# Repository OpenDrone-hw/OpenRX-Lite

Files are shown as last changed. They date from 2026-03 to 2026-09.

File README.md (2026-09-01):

# OpenRX Lite

Open-source 2.4 GHz ExpressLRS receiver for small FPV aircraft. OpenRX Lite
combines an ESP32-C3 and SX1281 with an on-board ceramic link antenna in a
10.0 x 11.5 mm board.

<p>
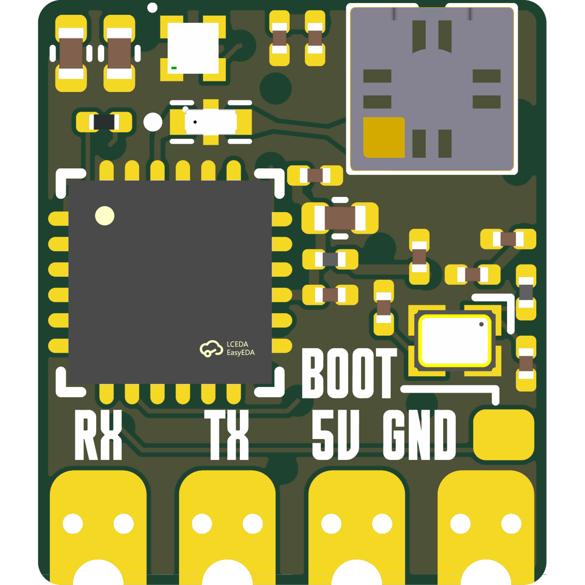
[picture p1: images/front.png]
OpenRX Lite front

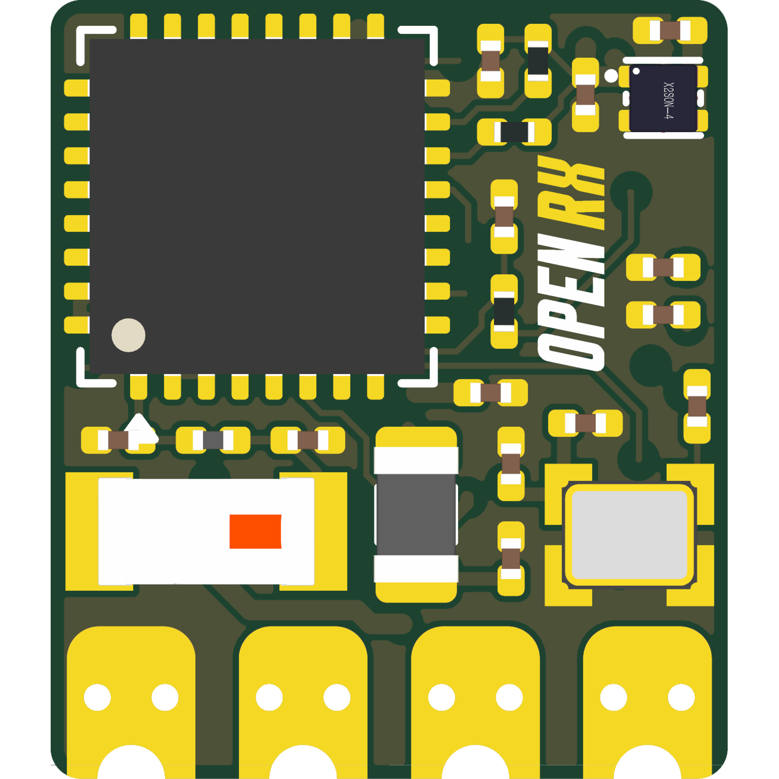
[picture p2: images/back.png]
OpenRX Lite back

</p>







## Specifications

| | |
|---|---|
| Band | 2.4 GHz |
| Radio | SX1281 |
| Antenna | On-board ceramic |
| Telemetry power | 13 dBm (20 mW) |
| Protocol | CRSF |
| MCU | ESP32-C3 |
| Input | 5 V pad |
| Firmware | ExpressLRS |
| Flashing | Betaflight passthrough or Wi-Fi |
| Dimensions | 10.0 x 11.5 mm |
| PCB | 6-layer, 1.0 mm |

Technical write-up, part list and layout constraints: [AGENTS.md](AGENTS.md).

## In the line

What pairs with what, and what is available:
[opendrone.be](https://opendrone.be).

## Contributing

See [CONTRIBUTING.md](CONTRIBUTING.md).

## License

Hardware licensed under [CERN-OHL-S-2.0](https://ohwr.org/cern_ohl_s_v2.txt),
see [LICENSE](LICENSE).

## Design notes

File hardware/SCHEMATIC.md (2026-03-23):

# OpenRX-Lite Schematic Documentation

Budget 2.4GHz ExpressLRS receiver. No PA/LNA, no UFL -- direct SX1281 to ceramic chip antenna.

- PCB: 16x12mm, 2-layer, 1.0mm thickness
- Target BOM: EUR 3-4
- Input: 3.3-5V from flight controller

## Block Diagram

```
                                    +3.3V
                                      |
  +-----+    +--------+    +---------+----------+
  | FC   |    |ME6211  |    |                    |
  | 5V---|----| LDO    |----|  ESP32-C3FH4       |
  | GND--|--+-| 3.3V   |    |  (QFN-32, 5x5mm)  |
  | TX---|--|-|--------|----| GPIO1/RX           |
  | RX---|--|-|--------|----| GPIO0/TX           |
  +-----+  | |        |    |                    |    SPI Bus
            | +--------+    |  GPIO4/SCK  -------+--------+
            |               |  GPIO7/MOSI -------+-----+  |
            |               |  GPIO6/MISO -------+--+  |  |
            |               |  GPIO8/NSS  -------+-+|  |  |
            |               |  GPIO5/DIO1 ------+| ||  |  |
            |               |  GPIO3/BUSY -----+|| ||  |  |
            |               |  GPIO2/NRST ----+||| ||  |  |
            |               |                 |||| ||  |  |
            |     40MHz     |  XTAL_P/N       |||| ||  |  |
            |    +-----+    |    |  |          |||| ||  |  |
            |    | XTAL|----+----+--+          |||| ||  |  |
            |    +-----+    |                  |||| ||  |  |
            |               | GPIO10 ---> WS2812B (opt)    |
            |               | GPIO9  ---> BOOT btn         |
            |               | GPIO18 ---> USB D- (TP)      |
            |               | GPIO19 ---> USB D+ (TP)      |
            |               +----------+   |||| ||  |  |
            |                              |||| ||  |  |
            |               +----------+   |||| ||  |  |
            |    52MHz      |SX1281    |   |||| ||  |  |
            |   +------+    |IMLTRT   |   |||| ||  |  |
            |   | TCXO |----|XTA      |   |||| ||  |  |
            |   +------+    |         |   |||| ||  |  |
            |               |NRESET---+---+||| ||  |  |
            |               |BUSY  --------+|| ||  |  |
            |               |DIO1  ---------+| ||  |  |
            |               |NSS   ----------+ ||  |  |
            |               |MISO  -------------+  |  |
            |               |MOSI  ----------------+  |
            |               |SCK   -------------------+
            |               |         |
            |               |  RFIO   |
            |               +----+----+
            |                    |
            |               L-match network
            |               2.2nH + 1.0pF
            |                    |
            |               +----------+
            |               | Ceramic  |
            |               | Antenna  |
            |               | 2450AT   |
            |               +----------+
            |
            +--- GND plane
```

## Power Supply (U3: ME6211C33M5G-N)

SOT-23-5, 500mA, LDO 3.3V regulator. LCSC C82942.

```
         5V IN
          |
          +--+--[C1 10uF]--+--GND
          |  |              |
          |  +--[C2 100nF]--+
          |
     +----+----+
     |1  VIN   |
     |         |
     |2  VOUT--+--+--[C3 22uF]--+--GND
     |         |  |              |
     |3  CE    |  +--[C4 100nF]--+
     |   (=VIN)|  |
     |4  GND   |  +--- 3.3V RAIL
     |5  NC    |
     +---------+
```

### Pin-by-pin: ME6211C33M5G-N (SOT-23-5)

| Pin | Name | Connection |
|-----|---|---|
| 1 | VIN | 5V input rail. C1 (10uF 0603 X5R) + C2 (100nF 0402 X7R) to GND |
| 2 | VOUT | 3.3V output rail. C3 (22uF 0603 X5R) + C4 (100nF 0402 X7R) to GND |
| 3 | CE (chip enable) | Tied to VIN (always on) |
| 4 | GND | Ground |
| 5 | NC | No connect |

## ESP32-C3FH4 (U1, QFN-32, 5x5mm)

LCSC C2858491. RISC-V single core, 160MHz, 4MB internal flash, WiFi+BLE.

### Pin-by-pin: ESP32-C3FH4 (QFN-32)

| Pin | Name | Connection | Notes |
|-----|---|---|---|
| 1 | GND | GND | |
| 2 | GND | GND | |
| 3 | 3V3 | 3.3V rail, 100nF (C5) to GND | Main power |
| 4 | EN (CHIP_EN) | 10k (R1) pull-up to 3.3V + 1uF (C6) to GND | RC delay per Espressif spec. Provides stable power-on reset. |
| 5 | GPIO4 | SX1281 SCK (pin 18) | SPI clock |
| 6 | GPIO5 | SX1281 DIO1 (pin 5) | Radio interrupt (active high) |
| 7 | GPIO6 | SX1281 MISO (pin 16) | SPI data from radio |
| 8 | GPIO7 | SX1281 MOSI (pin 17) | SPI data to radio |
| 9 | GPIO8 | SX1281 NSS (pin 19) + 10k (R2) pull-up to 3.3V | SPI chip select (active low). Pull-up keeps radio deselected during ESP boot. |
| 10 | GPIO9 | BOOT button (SW1) to GND + 10k (R3) pull-up to 3.3V | Hold low during reset to enter USB/UART bootloader. Internal pull-up exists but external recommended. |
| 11 | GPIO10 | WS2812B LED data (D1) | Optional status LED. Series 100R (R4) recommended. |
| 12 | GND | GND | |
| 13 | GPIO18 (USB_D-) | Test pad TP1 | Native USB for flashing. Optional -- can use UART instead. |
| 14 | GPIO19 (USB_D+) | Test pad TP2 | Native USB for flashing. Optional. |
| 15 | GPIO3 | SX1281 BUSY (pin 4) | Radio busy status (active high). Poll before SPI commands. |
| 16 | GPIO2 | SX1281 NRESETn (pin 3) | Radio hardware reset (active low). ESP drives low to reset SX1281. |
| 17 | GPIO1 (RX) | FC connector pad TX (CRSF from FC) | UART RX. FC TX connects to ESP RX. 3.3V logic. |
| 18 | GPIO0 (TX) | FC connector pad RX (CRSF to FC) | UART TX. ESP TX connects to FC RX. |
| 19 | GND | GND | |
| 20 | XTAL_P | 40MHz crystal (Y1) pin 1 + 10pF (C7) to GND | Crystal load cap. Place crystal close to pins 20/21. |
| 21 | XTAL_N | 40MHz crystal (Y1) pin 3 + 10pF (C8) to GND | Crystal load cap. |
| 22-30 | GND/NC | GND or NC per datasheet | Unused GPIO and supply pins tied to GND |
| 31 | GND | GND | |
| 32 | GND | GND | |
| EP | Exposed pad | GND | Thermal pad, multiple vias to ground plane |

**Critical notes for ESP32-C3FH4:**
- Pin 4 (EN) RC time constant: 10k * 1uF = 10ms. This ensures clean power-on reset.
- GPIO9 is the boot mode strapping pin. HIGH = normal boot from flash. LOW during reset = download mode.
- GPIO8 is also a strapping pin. Must be HIGH during boot (pull-up on NSS line handles this).
- GPIO2 is a strapping pin. Defaults to HIGH (floating). OK since SX1281 NRESET is active low.
- The ESP32-C3FH4 has 4MB flash internal -- no external flash needed.
- 40MHz crystal is mandatory. Cannot use internal RC oscillator for WiFi/BLE.
- Thermal pad MUST be soldered to GND with thermal vias.

## SX1281IMLTRT (U2, QFN-24, 4x4mm)

LCSC C2151551. 2.4GHz LoRa/FLRC/FSK transceiver. Used in LDO mode (no external inductor).

### Pin-by-pin: SX1281IMLTRT (QFN-24)

| Pin | Name | Connection | Notes |
|-----|---|---|---|
| 1 | VDD | 3.3V through 100nF (C9) to GND | Digital supply |
| 2 | VDD_IN | 3.3V through 100nF (C10) to GND | CRITICAL: Must be connected. Main power input for internal LDO/DC-DC. |
| 3 | NRESETn | ESP32-C3 GPIO2 (pin 16) + 10k (R5) pull-up to 3.3V + 100nF (C11) to GND | Active low reset. RC provides power-on reset. ESP can drive low for hard reset. |
| 4 | BUSY | ESP32-C3 GPIO3 (pin 15) | Active high when radio is processing a command. Poll before SPI transactions. |
| 5 | DIO1 | ESP32-C3 GPIO5 (pin 6) | Main interrupt output. Directly connected. |
| 6 | DIO2 | NC | Not used in this design. Can be used for RF switch control in designs with PA/LNA. |
| 7 | DIO3 | NC | Not used. Can output 32MHz clock for TCXO enable but we use always-on TCXO. |
| 8 | GND | GND | |
| 9 | GND | GND | |
| 10 | VR_PA | 470nF (C12) to GND | LDO mode: This is the PA regulator output. 470nF decoupling required. NO inductor (inductor only needed in DC-DC mode). |
| 11 | VDD | 3.3V through 100nF (C13) to GND | RF/analog supply |
| 12 | XTA | 52MHz TCXO output (Y2 pin 3) | TCXO clock input. AC coupling cap may be needed (10pF, C14) depending on TCXO output type. If TCXO is clipped sine output, direct connection OK. |
| 13 | XTB | NC (floating) | Only used in crystal mode. Leave floating for TCXO mode. |
| 14 | GND | GND | |
| 15 | RFIO | L-match network to antenna | See RF Path section below |
| 16 | MISO | ESP32-C3 GPIO6 (pin 7) | SPI data output |
| 17 | MOSI | ESP32-C3 GPIO7 (pin 8) | SPI data input |
| 18 | SCK | ESP32-C3 GPIO4 (pin 5) | SPI clock input |
| 19 | NSS | ESP32-C3 GPIO8 (pin 9) + 10k (R2) pull-up to 3.3V | SPI chip select, active low. Shared pull-up with ESP side. |
| 20 | GND | GND | |
| 21 | GND | GND | |
| 22 | GND | GND | |
| 23 | GND | GND | |
| 24 | GND | GND | |
| EP | Exposed pad | GND | Thermal pad. Multiple vias to GND plane. |

**Critical notes for SX1281:**
- LDO mode selected: VR_PA (pin 10) gets 470nF cap only. No inductor.
- DC-DC mode would require 15nH inductor on VR_PA but adds layout complexity on 2-layer board. Not worth it for a receiver.
- VDD_IN (pin 2) MUST be connected to 3.3V. Common mistake to leave it floating.
- TCXO mode: Set register UseRegulatorMode and configure TCXO in firmware. DIO3 can control TCXO power but we run TCXO always-on from 3.3V for simplicity.
- Max SPI clock: 16MHz. ESP32-C3 SPI peripheral should be configured accordingly.
- BUSY must be polled before every SPI transaction. Do not rely on timing.

## 52MHz TCXO (Y2: OW7EL89CENUNFAYLC-52M)

LCSC C22434896. SMD 2016-4P (2.0x1.6mm). YXC, 3.3V, +/-0.5ppm.

### Pin-by-pin: TCXO (SMD2016-4P)

| Pin | Name | Connection |
|-----|---|---|
| 1 | VDD | 3.3V through 100nF (C15) to GND |
| 2 | GND | GND |
| 3 | OUTPUT | SX1281 XTA (pin 12). Direct connection if clipped sine output. Add 10pF AC coupling cap (C14) if DC blocking needed. |
| 4 | GND | GND |

**Notes:**
- TCXO provides temperature-stable 52MHz reference. Prevents frequency drift disconnections that plague crystal-based ELRS receivers.
- +/-0.5ppm stability is excellent. SX1281 datasheet requires better than +/-5ppm for reliable FLRC mode.
- Always-on (powered from 3.3V rail directly). No DIO3 control needed.
- Place close to SX1281 XTA pin. Keep trace short and away from digital signals.

## 40MHz Crystal (Y1: CJ17-400001010B20)

LCSC C2875272. SMD 1612-4P (1.6x1.2mm). Changjing, 10pF load, +/-10ppm.

### Pin-by-pin: Crystal (SMD1612-4P)

| Pin | Name | Connection |
|-----|---|---|
| 1 | XIN | ESP32-C3 XTAL_P (pin 20) + 10pF (C7) to GND |
| 2 | GND | GND |
| 3 | XOUT | ESP32-C3 XTAL_N (pin 21) + 10pF (C8) to GND |
| 4 | GND | GND |

**Notes:**
- 10pF load caps match crystal specification. Actual capacitance seen by crystal = (C_load1 * C_load2) / (C_load1 + C_load2) + C_stray. With 10pF caps and ~2-3pF stray, effective load is ~7-8pF. May need to adjust to 12pF caps if frequency is off.
- Place as close to ESP32-C3 XTAL pins as possible. Route traces as short differential pair.
- Guard ring on GND plane around crystal traces recommended.
- Keep copper pour away from crystal on the other layer.

## RF Path (Antenna Matching)

No PA/LNA. Direct connection from SX1281 RFIO to ceramic antenna through L-match network.

```
SX1281          L-match              Ceramic Antenna
RFIO  ---[L1 2.2nH]---+---[feed]--- 2450AT18A100E
(pin 15)               |             (Johanson)
                   [C16 1.0pF]
                       |
                      GND
```

### Components:
- L1: 2.2nH inductor, 0402, high-Q (>30 at 2.4GHz). LCSC basic part preferred.
- C16: 1.0pF capacitor, 0402, C0G/NP0. Tight tolerance (+/-0.1pF if possible).

### Ceramic Antenna: 2450AT18A100E (ANT1)

LCSC C89334. Johanson, 3.2x1.6mm chip antenna.

**Notes:**
- Antenna MUST be placed at PCB edge with ground plane keepout per Johanson application note.
- Minimum 1mm clearance from antenna feed to GND pour on top layer.
- Ground plane on bottom layer should extend under antenna for return path.
- Antenna impedance is nominally 50 ohm but varies with ground plane geometry. L-match values (2.2nH/1.0pF) are starting points -- tune with VNA on actual PCB.
- No copper (signal or ground) on the same layer as antenna within keepout zone.
- Performance will be significantly worse than external antenna. Expected range: 200-500m line of sight with ELRS 500Hz mode. Adequate for typical FPV use (proximity/indoor/whoops).

## WS2812B LED (D1, Optional)

Standard addressable RGB LED for status indication.

| Connection | Detail |
|---|---|
| VDD | 3.3V (WS2812B works at 3.3V, some variants need 5V -- check datasheet) |
| DIN | ESP32-C3 GPIO10 (pin 11) through 100R series resistor (R4) |
| DOUT | NC |
| GND | GND |
| Decoupling | 100nF (C17) close to VDD pin |

Note: WS2812B is optional. Omit to save BOM cost and board space. ELRS firmware can function without LED.

## Boot Button (SW1)

Tactile switch, normally open.

| Connection | Detail |
|---|---|
| One side | ESP32-C3 GPIO9 (pin 10) |
| Other side | GND |
| Pull-up | 10k (R3) from GPIO9 to 3.3V |

Hold button during power-on or reset to enter bootloader (USB or UART download mode).

Note: For production, this can be replaced with solder pads or omitted entirely if UART flashing via FC connection is sufficient. ELRS uses its own bootloader passthrough via UART.

## Connector Pads (J1)

4 castellated or solder pads, 1.27mm pitch, at PCB edge.

| Pad | Signal | Notes |
|-----|---|---|
| 1 | 5V | Power input from FC. 3.3-5V range (LDO input). |
| 2 | GND | Ground |
| 3 | TX | ESP32-C3 GPIO0/TX. CRSF data TO flight controller. Connect to FC RX pad. |
| 4 | RX | ESP32-C3 GPIO1/RX. CRSF data FROM flight controller. Connect to FC TX pad. |

## Test Pads

| Pad | Signal | Notes |
|-----|---|---|
| TP1 | USB D- | ESP32-C3 GPIO18. For USB flashing during development. |
| TP2 | USB D+ | ESP32-C3 GPIO19. For USB flashing during development. |

## Complete Decoupling Capacitor Summary

| Designator | Value | Package | Location | IC/Pin |
|---|---|---|---|---|
| C1 | 10uF | 0603 X5R 10V | LDO input | U3 VIN |
| C2 | 100nF | 0402 X7R 16V | LDO input | U3 VIN |
| C3 | 22uF | 0603 X5R 10V | LDO output | U3 VOUT |
| C4 | 100nF | 0402 X7R 16V | LDO output | U3 VOUT |
| C5 | 100nF | 0402 X7R 16V | ESP32 3V3 | U1 pin 3 |
| C6 | 1uF | 0402 X5R 10V | ESP32 EN | U1 pin 4 (with R1) |
| C7 | 10pF | 0402 C0G 50V | Crystal load | U1 XTAL_P (pin 20) |
| C8 | 10pF | 0402 C0G 50V | Crystal load | U1 XTAL_N (pin 21) |
| C9 | 100nF | 0402 X7R 16V | SX1281 VDD | U2 pin 1 |
| C10 | 100nF | 0402 X7R 16V | SX1281 VDD_IN | U2 pin 2 |
| C11 | 100nF | 0402 X7R 16V | SX1281 NRESET | U2 pin 3 (with R5) |
| C12 | 470nF | 0402 X5R 10V | SX1281 VR_PA | U2 pin 10 (LDO mode) |
| C13 | 100nF | 0402 X7R 16V | SX1281 VDD | U2 pin 11 |
| C14 | 10pF | 0402 C0G 50V | TCXO AC coupling | Y2 out to U2 XTA (optional) |
| C15 | 100nF | 0402 X7R 16V | TCXO VDD | Y2 pin 1 |
| C16 | 1.0pF | 0402 C0G 50V | Antenna match | Shunt to GND in L-match |
| C17 | 100nF | 0402 X7R 16V | WS2812B VDD | D1 (optional) |

## Complete Resistor Summary

| Designator | Value | Package | Location |
|---|---|---|---|
| R1 | 10k | 0402 | ESP32 EN pull-up |
| R2 | 10k | 0402 | SPI NSS pull-up (shared ESP/SX1281) |
| R3 | 10k | 0402 | BOOT button pull-up |
| R4 | 100R | 0402 | WS2812B data series resistor (optional) |
| R5 | 10k | 0402 | SX1281 NRESET pull-up |

## Complete Inductor Summary

| Designator | Value | Package | Location |
|---|---|---|---|
| L1 | 2.2nH | 0402 | Antenna L-match series inductor |

## Design Notes and Considerations

### Power Budget
- ESP32-C3 active (WiFi off, CPU running): ~30mA
- SX1281 RX mode: ~7mA
- SX1281 TX mode (no PA): ~25mA at +12.5dBm
- TCXO: ~1.5mA
- WS2812B: ~1mA idle, ~20mA full white
- Total typical (RX mode): ~40mA
- ME6211 500mA capacity provides ample margin

### Layout Priorities (2-layer board)
1. SX1281 ground pad: Maximize thermal vias to bottom GND plane
2. ESP32-C3 ground pad: Same treatment
3. Crystal placement: As close to ESP XTAL pins as physically possible
4. TCXO placement: As close to SX1281 XTA as possible
5. Antenna: At PCB edge, ground plane keepout per Johanson app note
6. Decoupling caps: Each cap within 1mm of its associated IC pin
7. SPI traces: Keep short, matched length not critical at 16MHz max
8. RF trace (RFIO to antenna): 50 ohm controlled impedance if possible. On 2-layer 1.0mm FR4, approximately 1.8mm trace width for 50 ohm microstrip. Short trace length minimizes mismatch impact.

### 2-Layer Stackup (JLCPCB 1.0mm)
- Top: Components, signal routing, RF trace
- Bottom: Continuous GND plane (maximise pour). Route signals on top only where possible.

### Firmware Considerations
- ExpressLRS firmware must be configured for:
  - SX1281 (not SX1280 -- SX1281 has LNA built in)
  - TCXO mode (not crystal)
  - LDO mode (not DC-DC)
  - No PA/LNA control pins
  - GPIO mappings matching this schematic
- CRSF protocol on UART at 420000 baud (ELRS default)
- Binding phrase set in firmware build

### Known Limitations
- No diversity (single antenna, single radio)
- No PA: TX power limited to SX1281 native +12.5dBm max
- No LNA: RX sensitivity limited to SX1281 native (~-105dBm for LoRa, ~-98dBm for FLRC)
- Range estimate: 200-500m LOS at 500Hz, 1-2km at 50Hz. Adequate for proximity/indoor/whoop flying.
- 2-layer RF: Impedance control less precise than 4-layer. Antenna match will need bench tuning.
- Ceramic antenna: ~2-3dB gain penalty vs external dipole/T-antenna

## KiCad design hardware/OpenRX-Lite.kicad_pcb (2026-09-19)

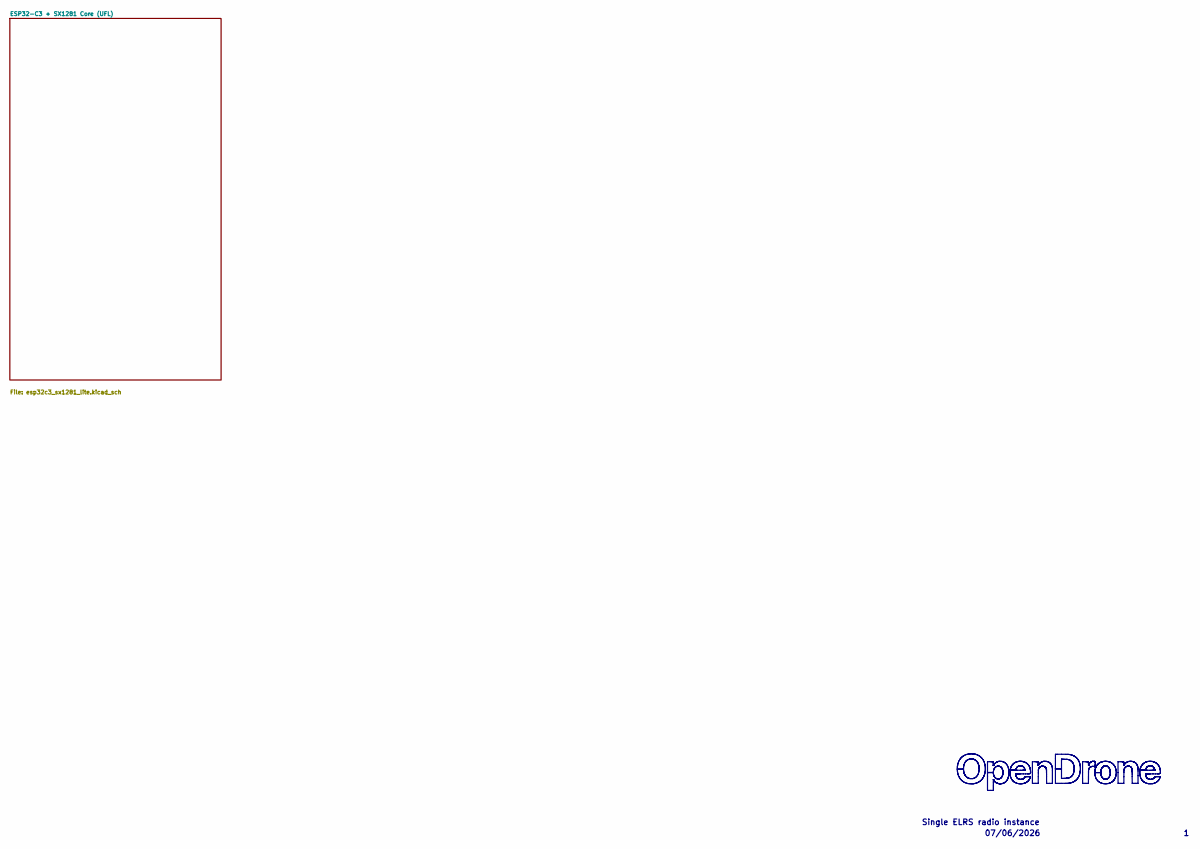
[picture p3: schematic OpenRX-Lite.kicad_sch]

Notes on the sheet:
07/06/2026
Single ELRS radio instance

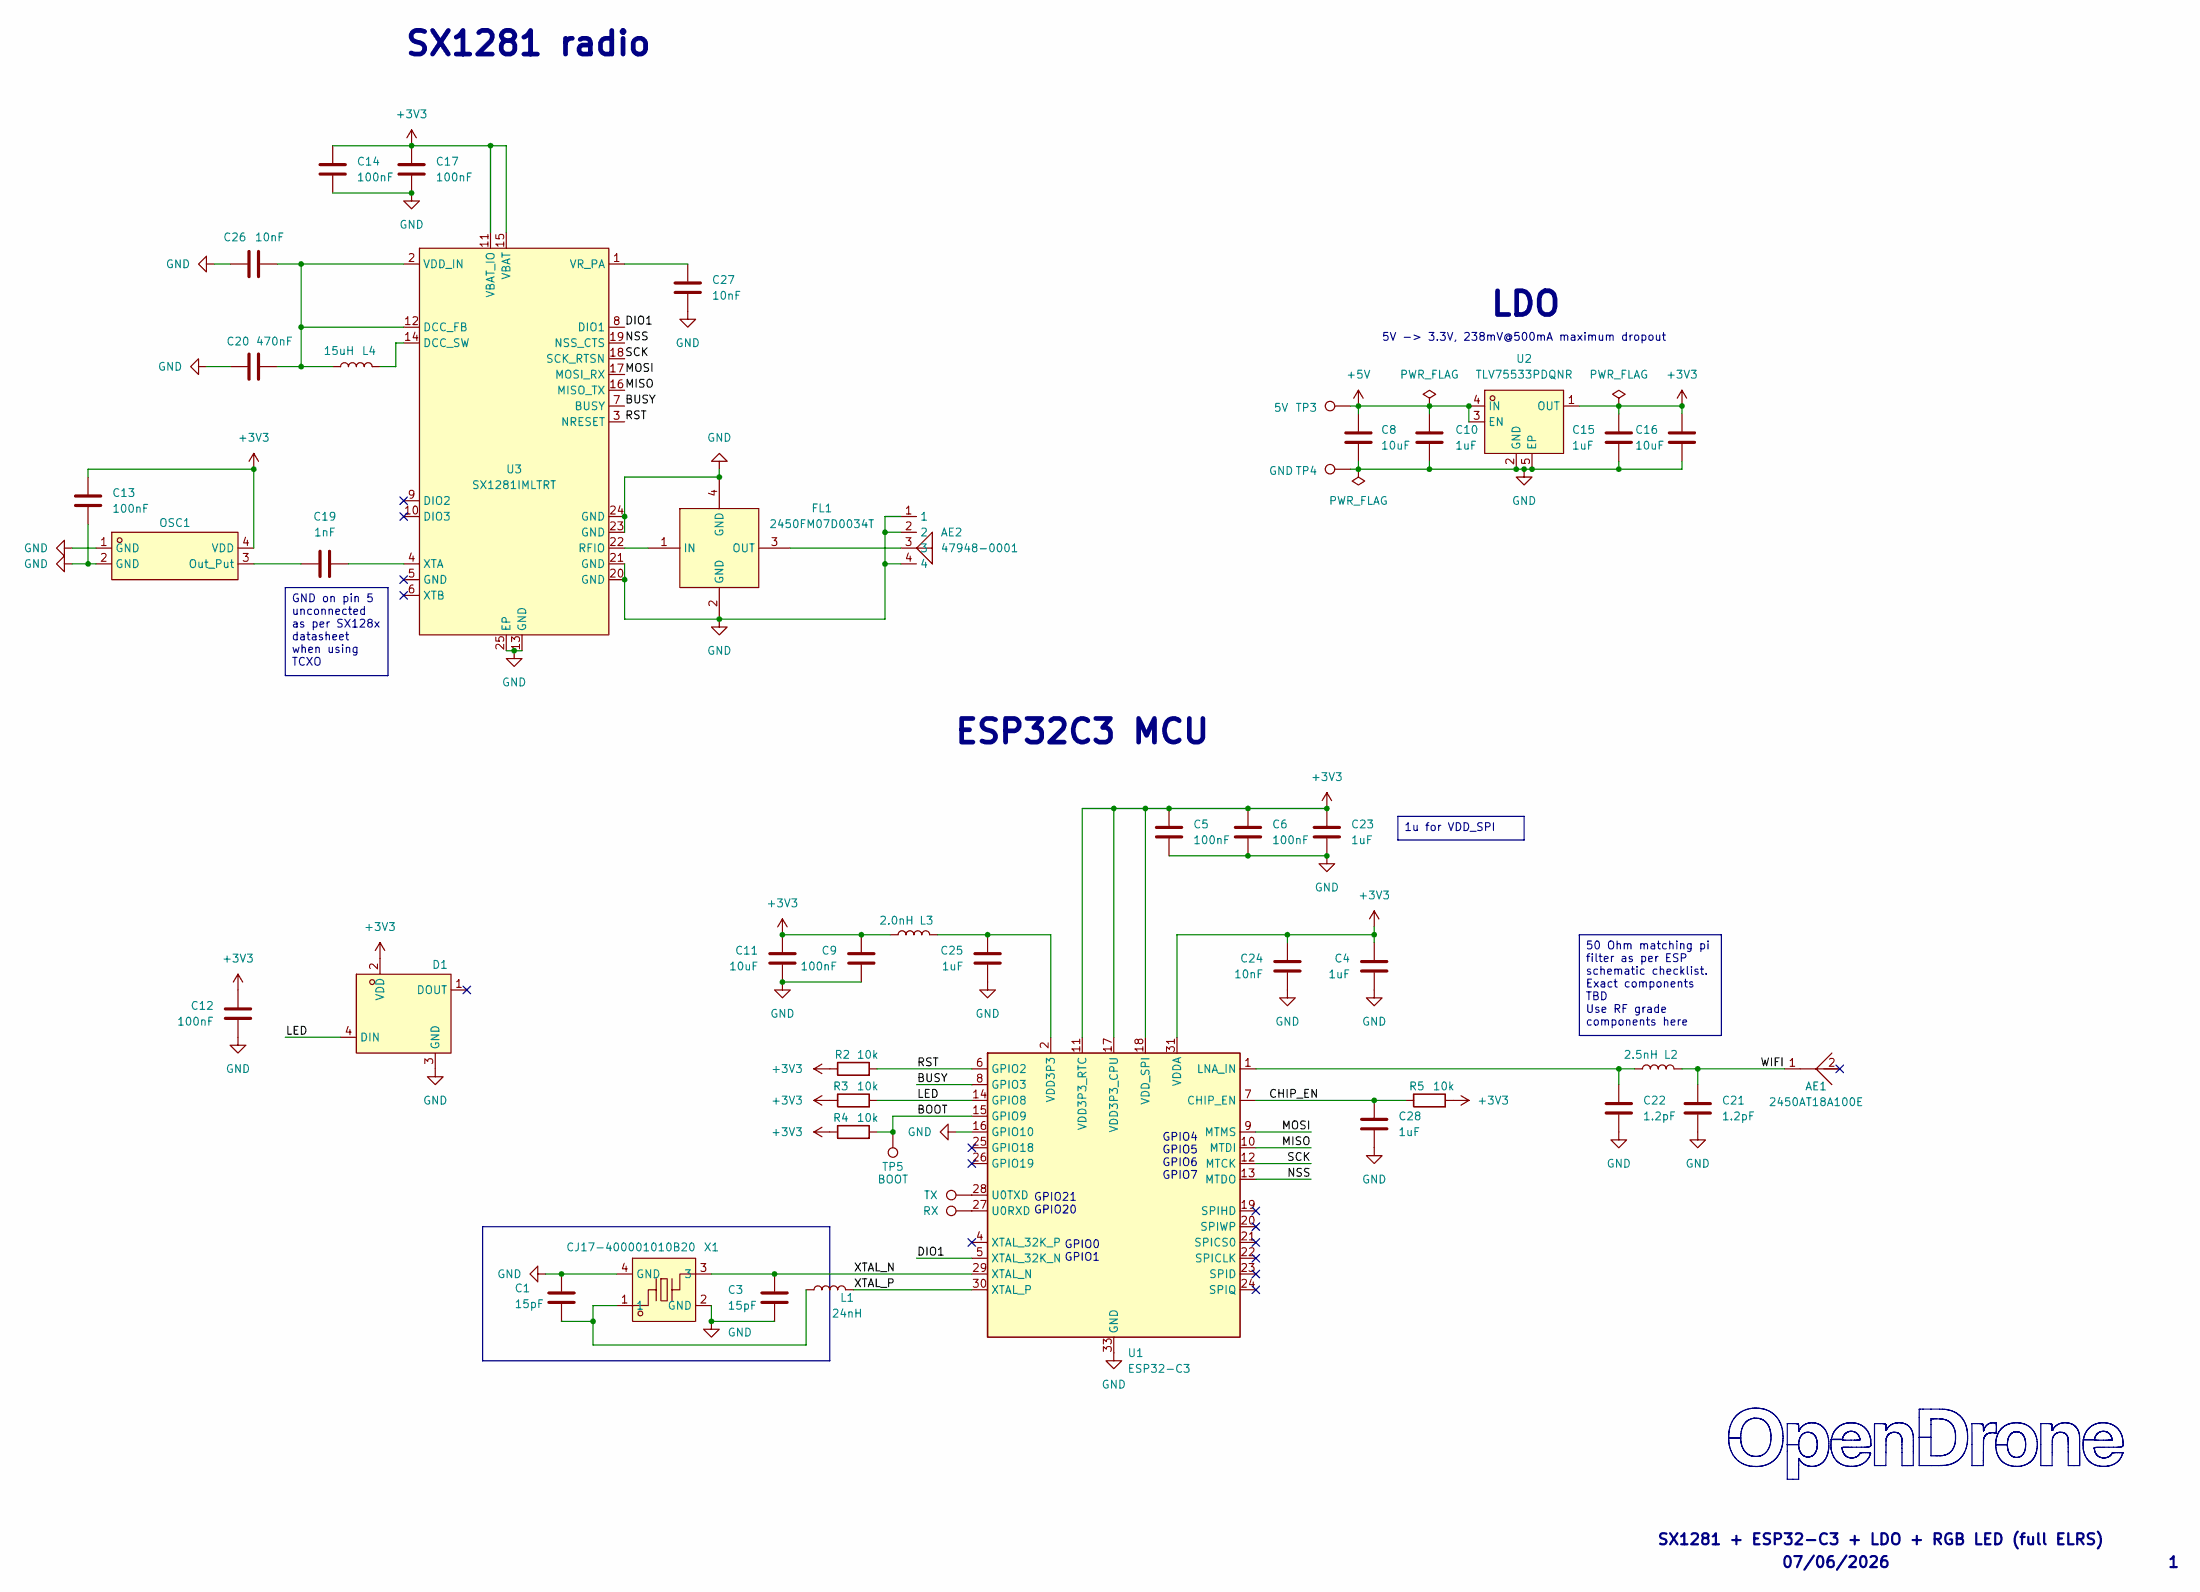
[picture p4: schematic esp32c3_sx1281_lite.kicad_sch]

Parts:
AE1: 2450AT18A100E; ANT-SMD_L3.2-W1.6; MPN 2450AT18A100E; LCSC Part C89334
AE2: 47948-0001; ANT-SMD_47948-0001; MPN 479480001; LCSC C152351
C1, C3: 15pF; C_0201_0603Metric; MPN GRM0335C1H150JA01D; LCSC C85891
C4, C10, C15, C23, C25, C28: 1uF; C_0201_0603Metric; MPN GRM033R61A105ME44D; LCSC C76935
C5, C6, C9, C12, C13, C14, C17: 100nF; C_0201_0603Metric; MPN GRM033R61E104KE14D; LCSC C76939
C8, C16: 10uF; C_0402_1005Metric; MPN CL05A106MQ5NUNC; LCSC C15525
C11: 10uF; C_0402_1005Metric; MPN GRM155R60J106ME44D; LCSC C76991
C19: 1nF; C_0201_0603Metric; MPN 0201B102K500NT; LCSC C66942
C20: 470nF; C_0201_0603Metric; MPN GRM033R60J474KE90D; LCSC C85926
C21, C22: 1.2pF; C_0201_0603Metric; MPN GRM0335C1H1R2BA01D; LCSC C85895
C24, C26, C27: 10nF; C_0201_0603Metric; MPN GRM033R61A103KA01J; LCSC C2168164
D1: XL-1010RGBC-WS2812B; LED-SMD_4P-L1.0-W1.0-TL_XL-1010RGBC-WS2812B; MPN XL-1010RGBC-2812B; LCSC C5349953
FL1: 2450FM07D0034T; FILTER-SMD_4P-L1.0-W0.5-L; MPN 2450FM07D0034T; LCSC Part_1 C2651081
L1: 24nH; L_0201_0603Metric; MPN LQP03TN24NH02D; LCSC C206441
L2: 2.5nH; L_0201_0603Metric; MPN LQP03TN2N5C02D; LCSC C206435
L3: 2.0nH; L_0201_0603Metric; MPN LQP03TN2N0B02D; LCSC C86125
L4: 15uH; L_0805_2012Metric; MPN MLZ2012M150WT000; LCSC C383402
OSC1: OW7EL89CENUNFAYLC-52M; OSC-SMD_4P-L2.0-W1.6-BL_TXC_7Z; MPN OW7EL89CENUNFAYLC-52M; LCSC Part C22434896
R2, R3, R4, R5: 10k; R_0201_0603Metric; MPN RC0201FR-0710KL; LCSC C106225
TP1: RX; SolderPad_1.2x2.0mm
TP2: TX; SolderPad_1.2x2.0mm
TP3: 5V; SolderPad_1.2x2.0mm
TP4: GND; SolderPad_1.2x2.0mm
TP5: BOOT; SolderPad_1.2x2.0mm
U1: ESP32-C3; QFN-32-1EP_5x5mm_P0.5mm_EP3.7x3.7mm; MPN ESP32-C3FH4; LCSC C2858491
U2: TLV75533PDQNR; X2SON-4_L1.0-W1.0-P0.65-TL-EP; MPN TLV75533PDQNR; LCSC Part C2861882
U3: SX1281IMLTRT; QFN-24_L4.0-W4.0-P0.50-TL-EP2.6; MPN SX1281IMLTRT; LCSC Part C2151551
X1: CJ17-400001010B20; CRYSTAL-SMD_4P-L1.6-W1.2-BL; MPN CJ17-400001010B20; LCSC Part C2875272

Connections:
+3V3: C4.1, C5.1, C6.1, C9.1, C11.1, C12.1, C13.1, C14.1, C15.1, C16.1, C17.1, C23.1, C24.1, D1.2 (VDD), L3.2, OSC1.4 (VDD), R2.1, R3.1, R4.1, R5.2, U1.11 (VDD3P3_RTC), U1.17 (VDD3P3_CPU), U1.18 (VDD_SPI), U1.31 (VDDA), U1.32 (VDDA), U2.1 (OUT), U3.11 (VBAT_IO), U3.15 (VBAT)
+5V: C8.1, C10.1, TP3.1 (1_1), U2.3 (EN), U2.4 (IN)
/ESP32-C3 + SX1281 Core (UFL)/BOOT: R4.2, TP5.1 (1_1), U1.15 (GPIO9)
/ESP32-C3 + SX1281 Core (UFL)/BUSY: U1.8 (GPIO3), U3.7 (BUSY)
/ESP32-C3 + SX1281 Core (UFL)/CHIP_EN: C28.1, R5.1, U1.7 (CHIP_EN)
/ESP32-C3 + SX1281 Core (UFL)/DIO1: U1.5 (XTAL_32K_N), U3.8 (DIO1)
/ESP32-C3 + SX1281 Core (UFL)/LED: D1.4 (DIN), R3.2, U1.14 (GPIO8)
/ESP32-C3 + SX1281 Core (UFL)/MISO: U1.10 (MTDI), U3.16 (MISO_TX)
/ESP32-C3 + SX1281 Core (UFL)/MOSI: U1.9 (MTMS), U3.17 (MOSI_RX)
/ESP32-C3 + SX1281 Core (UFL)/NSS: U1.13 (MTDO), U3.19 (NSS_CTS)
/ESP32-C3 + SX1281 Core (UFL)/RST: R2.2, U1.6 (GPIO2), U3.3 (NRESET)
/ESP32-C3 + SX1281 Core (UFL)/SCK: U1.12 (MTCK), U3.18 (SCK_RTSN)
/ESP32-C3 + SX1281 Core (UFL)/WIFI: AE1.1, C21.1, L2.1
/ESP32-C3 + SX1281 Core (UFL)/XTAL_N: C3.1, U1.29 (XTAL_N), X1.3
/ESP32-C3 + SX1281 Core (UFL)/XTAL_P: L1.2, U1.30 (XTAL_P)
GND: AE2.1, AE2.2, AE2.4, C1.2, C3.2, C4.2, C5.2, C6.2, C8.2, C9.2, C10.2, C11.2, C12.2, C13.2, C14.2, C15.2, C16.2, C17.2, C20.1, C21.2, C22.2, C23.2, C24.2, C25.2, C26.1, C27.2, C28.2, D1.3 (GND), FL1.2 (GND), FL1.4 (GND), OSC1.1 (GND), OSC1.2 (GND), TP4.1 (1_1), U1.16 (GPIO10), U1.33 (GND), U2.2 (GND), U2.5 (EP), U3.13 (GND), U3.20 (GND), U3.21 (GND), U3.23 (GND), U3.24 (GND), U3.25 (EP), X1.2 (GND), X1.4 (GND)
unnamed: C1.1, L1.1, X1.1
unnamed: C25.1, L3.1, U1.2 (VDD3P3), U1.3 (VDD3P3)
unnamed: FL1.1 (IN), U3.22 (RFIO)
unnamed: AE2.3, FL1.3 (OUT)
unnamed: C19.1, OSC1.3 (Out_Put)
unnamed: C22.1, L2.2, U1.1 (LNA_IN)
unnamed: TP1.1 (1_1), U1.27 (U0RXD)
unnamed: TP2.1 (1_1), U1.28 (U0TXD)
unnamed: C20.2, C26.2, L4.1, U3.2 (VDD_IN), U3.12 (DCC_FB)
unnamed: L4.2, U3.14 (DCC_SW)
unnamed: C27.1, U3.1 (VR_PA)
unnamed: C19.2, U3.4 (XTA)

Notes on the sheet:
5V -> 3.3V, 238mV@500mA maximum dropout
GPIO0 GPIO1
SX1281 + ESP32-C3 + LDO + RGB LED (full ELRS)
GPIO21 GPIO20
GPIO4 GPIO5 GPIO6 GPIO7
SX1281 radio
LDO
ESP32C3 MCU
07/06/2026
GND on pin 5 unconnected as per SX128x datasheet when using TCXO
1u for VDD_SPI
50 Ohm matching pi filter as per ESP schematic checklist. Exact components TBD Use RF grade components here

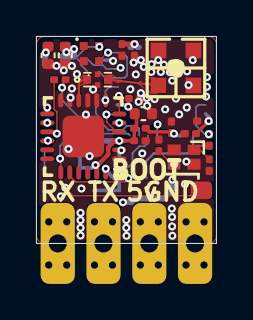
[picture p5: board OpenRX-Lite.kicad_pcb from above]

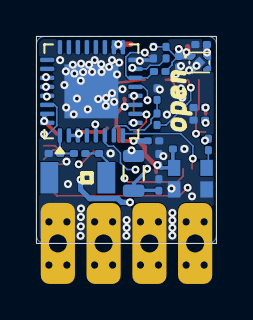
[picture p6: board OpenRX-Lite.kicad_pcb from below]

Board: 6 copper layers, 10.0 x 11.5 mm, 47 parts (22 on the bottom side), 28 nets.

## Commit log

2026-03-23 Initial repo: 6-receiver product lineup, core BOM, shared datasheets
    OpenRX is an open-source ExpressLRS 4.0 receiver family covering
    budget nano to Xrossband Gemini. All designs use ESP32-C3 MCU with
    SX1281 (2.4GHz) or LR1121 (dual-band) RF transceivers.
    CERN-OHL-S v2 licensed. Part of the OpenDrone ecosystem.
2026-03-23 Add OpenRX-Lite: budget 2.4GHz receiver (ESP32-C3 + SX1281)
    Smallest/cheapest receiver. No PA/LNA, ceramic antenna, 16x12mm.
    Includes SCHEMATIC.md, BOM.md, imported LCSC libs, datasheets.
    KiCad schematic/PCB are starter shells awaiting capture.
    [OpenRX-Lite.kicad_pcb, OpenRX-Lite.kicad_sch]
2026-03-23 Consolidate docs: 1 README + KICAD_WORKFLOW + 1 DESIGN.md per receiver
    - Merge SCHEMATIC.md + BOM.md into single DESIGN.md per receiver
    - Delete OPENRX_ELRS_4_RECEIVER_PORTFOLIO.md (content integrated)
    - Delete REPO_AUDIT_2026-03-23.md (issues addressed)
    - Fold CORE_BOM into README.md architecture table
    - Rename KICAD_WORKFLOW_AND_ELRS_COMPATIBILITY.md to KICAD_WORKFLOW.md
    - Rewrite KICAD_WORKFLOW with step-by-step capture instructions
    - Add shared libs and starter shared sheet from audit agent
    [OpenRX-Lite.kicad_sch]
2026-03-23 Fix all DESIGN.md: RFX2401C, DEA LPF, LR1121 pinout, FEM control
    - Lite: remove L-match network, use DEA102700LT-6307A2 only
    - Nano: clarify DEA LPF path, mark 0.3pF as mandatory, SE2431L as EOL
    - 900: fix LR1121 RFSW description, confirm 4x4mm package
    - Dual: SE2431L→RFX2401C, FEM via LR1121 RFSW not MCU GPIO, BOM $9→$7.62
    - PWM: SE2431L→RFX2401C, DEA LPF + 0.3pF path, BOM $7.40→$6.02
    - Gemini: SE2431L→RFX2401C, fix FEM control model, BOM $10.84→$9.46
    [OpenRX-Lite.kicad_sch]
2026-03-23 Update all DESIGN.md: TLV75533 X2SON LDO, XL-1010 1x1mm LED
    - Lite/Nano/900/Dual: ME6211 SOT-23-5 → TLV75533PDQNR X2SON-4 (1x1mm)
    - Gemini: keeps AP2112K (600mA needed for dual radios)
    - PWM: keeps AMS1117 (needs >6V input range)
    - All: WS2812B-2020 → XL-1010RGBC-WS2812B (1x1mm)
    - Updated cap values for TLV755 (1uF local + 10uF bulk)
    [OpenRX-Lite.kicad_sch]
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2026-03-23 Unify library tables, import RFX2401C, Lite schematic capture
    - All 6 projects now share OpenRX-Shared + OpenRX-Lite lib tables
    - Import RFX2401C (C19213) into shared library with 3D model path fix
    - OpenRX-Lite schematic: 0 ERC errors (captured in KiCad GUI)
    - Add .gitignore for .lck and .history files
    [OpenRX-Lite.kicad_pcb, OpenRX-Lite.kicad_sch]
2026-03-23 Separate Lite and Nano schematics, stop sharing one file
    Sharing one .kicad_sch between projects doesn't work - KiCad
    overwrites instance data when either project saves.
    - Lite: restored pre-Nano schematic as local esp32c3_sx1281_lite.kicad_sch
    - Nano: copied current shared sheet as local esp32c3_sx1281_rx_core.kicad_sch
    - Each project now has its own schematic file
    [OpenRX-Lite.kicad_sch, esp32c3_sx1281_lite.kicad_sch]
2026-03-23 Lite + Nano schematics: LCSC fields, fix 10uF to 0402, drop 0.3pF cap
    - All passives in both schematics have LCSC fields
    - 10uF caps fixed from 0201 to 0402 (C15525)
    - Nano C22 (0.3pF): removed discrete cap, use trace capacitance instead
    - 0 ERC errors on both schematics
    [esp32c3_sx1281_lite.kicad_sch]
2026-03-23 OpenRX-900: add all LCSC fields, fix 4.7uF to 0402
    - C20 (4.7uF): C23733, footprint fixed from 0201 to 0402
    - R5/R6/R7 (100k): C25741, RFSW pull-downs
    - L1 (10uH): C1035, 0603 DC-DC inductor
    - U4 (LR1121): C7498014
    - U5 (32MHz TCXO): C22434888
    - T1 (Johanson IPD): C19842466
    - JP1 (UFL): C88374
    - 0 ERC errors, all components have LCSC fields
2026-03-23 Fix crystal load caps: 10pF → 18pF (C71153) on all 4 receivers
    CJ17-400001010B20 crystal has CL=10pF. With 10pF load caps and
    ~2pF stray, effective load was only 7pF (30% low). Changed to 18pF
    giving ~11pF effective load, matching the crystal spec.
    C71153 = Samsung CL03C180JA3NNNC, 18pF C0G 25V 0201.
    [esp32c3_sx1281_lite.kicad_sch]
2026-03-23 Fix Gemini crystal load caps to 18pF (C62164), matching Lite and Mono
    [OpenRX-Lite.kicad_pcb, esp32c3_sx1281_lite.kicad_sch]
2026-03-23 OpenRX-Gemini: dual LR1121 schematic complete, 0 ERC errors
    - Radio 1 (U4): sub-GHz via Johanson IPD → JP1 UFL
    - Radio 2 (U9): 2.4GHz via RFX2401C (U10) → DEA (USB2) → JP3 UFL
    - Shared SPI bus (SCK/MISO/MOSI), separate NSS/IRQ/BUSY/RST per radio
    - Radio 2 control: GPIO10=NSS2, GPIO9=IRQ2, GPIO1=BUSY2, GPIO0=RST2
    - FEM driven by Radio 2 RFSW (DIO5→RXEN, DIO6→TXEN)
    - Radio 1 DIO5/DIO6 have 100k pull-downs (disconnected from FEM)
    - No LED (GPIO10 used for NSS2), no boot button (GPIO9 used for IRQ2)
    - Still needs: 10k pull-up on NSS2
    [esp32c3_sx1281_lite.kicad_sch]
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2026-03-23 Swap all solder pads to 1.2x2.0mm rounded (25%) across Lite, Mono, Gemini
    [esp32c3_sx1281_lite.kicad_sch]
2026-03-23 Swap 32MHz TCXO to smaller 2016 package (C22381772)
    OW2EL89 (3225, 3.2x2.5mm) → OW7EL89 (2016, 2.0x1.6mm)
    Same YXC family, same pinout, same specs. Saves 1.2x0.9mm per TCXO.
    Affects Mono (1x) and Gemini (2x).
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2026-03-23 Final topology: Mono + Gemini netlist with SKY13588 RF switch
    - SKY13588-460LF imported into shared library
    - Complete netlist for Mono (1×LR1121 + SKY13588 + Johanson IPD + DEA LPF → 1 UFL)
    - Gemini = 2× Mono RF chains + ESP32-C3 True Diversity GPIO mapping
    - GPIO maps match official ELRS Generic C3 LR1121 and True Diversity targets
    - Routing notes for RF paths included
    - Mono needs complete GPIO rewire to match ELRS target
2026-03-23 FINAL_NETLIST v3: SKY13588 as band combiner, RFX2401C kept for 100mW
    Based on RadioMaster XR4 teardown analysis:
    - SKY13588 serves as both sub-GHz path switch AND band combiner
    - Johanson IPD in direct-tie mode (RX/TX_LP/TX_HP joined) → SKY13588 J1
    - 2.4GHz: RFIO_HF → DEA LPF → RFX2401C → SKY13588 J2
    - SKY13588 RFC → DC block → UFL → dual-band antenna
    - RFX2401C kept for 100mW market parity
    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
2026-03-24 Repo cleanup: final state for handoff
    - Clean README with architecture, BOM, CE notes, status
    - Remove dated analysis files (absorbed into FINAL_NETLIST + KICAD_WORKFLOW)
    - Remove stale OpenRX-Dual (archived), ERC reports, backups, prl files
    - Updated .gitignore for .kicad_dru, production backups
    - CERN-OHL-S v2 license confirmed
    - 3 active projects: Lite, Mono, Gemini
    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
    [OpenRX-Lite.kicad_pcb, esp32c3_sx1281_lite.kicad_sch]
2026-04-06 Update schematics: Mono RF rewiring, SKY13414 port mapping, shared libs
    Mono: disconnect IPD TX_LP (unused by ELRS), route TX_HP→RF3, RX→RF1,
    RFX2401C ANT→RF4. Matches BetaFPV SuperX topology.
    [OpenRX-Lite.kicad_pcb, esp32c3_sx1281_lite.kicad_sch]
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2026-04-06 Update all DESIGN.md docs: RF paths, GPIO maps, rfsw_ctrl, known bugs
    - Mono: new SKY13414 port mapping (RF1=RX, RF3=TX_HP, RF4=2.4GHz),
    rfsw_ctrl [15,0,0,8,8,14,0,13], GPIO map, impedance notes
    - Lite/Lite-UFL: GPIO map, no-boot-button note, SPI pin difference
    - Gemini: document DIO7-2/DIO8-2 wiring bug, stale component list
    - README: current lineup table
2026-04-21 initial routing for all
    [esp32c3_sx1281_lite.kicad_sch]
2026-04-27 final route
    [OpenRX-Lite.kicad_pcb]
2026-04-28 Set via netclass + dimension defaults to 0.3/0.2mm on all 4 boards
    [OpenRX-Lite.kicad_pcb]
2026-04-28 switch to 0.2mm vias
    [OpenRX-Lite.kicad_pcb]
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2026-05-08 OpenRX Lite (UFL + molex)
    [OpenRX-Lite.kicad_pcb, OpenRX-Lite.kicad_sch, esp32c3_sx1281_lite.kicad_sch]
2026-05-13 fab and placement output for combined order
    [OpenRX-Lite.csv]
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2026-06-07 docs: reconcile README against schematics, add DESIGN_NOTES + all-variant renders
    - README rewritten against schematic/netlist ground truth (OpenFC-Lite-Mini-style
    layout, all four variants' front/back renders side-by-side).
    - Corrected antenna roles: AE1 (2450AT18A100E ceramic) is the ESP32-C3 Wi-Fi/OTA
    antenna (net WIFI) on every variant; the ELRS link antenna is FL1-OUT's load —
    47948-0001 chip antenna on Lite, U.FL on Lite-UFL/Mono/Gemini.
    - Pad pinout + per-variant pin map derived from netlists and ELRS target JSON.
    - Corrected: two distinct radio TCXOs (52 MHz SX1281 / 32 MHz LR1121); only Gemini
    has a tactile button; per-variant LED GPIO.
    - DESIGN_NOTES.md mirrors the on-can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
2026-08-05 Lite/Lite-UFL: ELRS target pin remap and RGB LED
    Corrected SX1281 SPI pin map (miso/mosi/sck/dio1/nss) and switched
    from plain LED on GPIO10 to WS2812 RGB on GPIO8, matching the boards.
2026-08-05 docs: adopt OpenDrone repo standard
    README restructured to the standard section order; deep antenna, pad,
    pin-map, and firmware-target detail relocated to a new family DESIGN.md.
    Per-variant DESIGN.md files reconciled against the committed schematics,
    PCBs, and ELRS target JSON: SKY13373-460LF (not SKY13414), current
    radio_rfsw_ctrl values, real Gemini sheet hierarchy and refdes, Lite
    DESIGN.md no longer a copy of the Lite-UFL one. Adds CONTRIBUTING.md,
    AGENTS.md, CHANGELOG.md.
    Fact-check fixes: board sizes at Edge.Cuts centerline, KiCad 10 (not
    9/10), library claim corrected to OpenRX-Shared + Incutec submodule +
    embedded stock footprints, ELRS targets described as in-repo (not
    upstream),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
2026-08-05 changed 3.3V supply on clocks, added text, enlarged pads
    [OpenRX-Lite.kicad_pcb]
2026-08-06 Rewrite CONTRIBUTING for humans: file locking, render proof, sign-off
    KiCad files cannot be merged, so the doc now leads with claiming files via
    git lfs lock and issue-first discussion, the convention used by LumenPnP and
    Ultimate Hacking Keyboard. Adds .gitattributes marking design files lockable.
    Drops the internal documentation-style rule that meant nothing to contributors.
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2026-08-06 Fix contradictions and duplicated information
    Contradictions:
    - Restore shared/libs/OpenRX-Shared.kicad_sym, dropped by accident in ec2c4f2.
    All 7 sym-lib-tables point at it and the schematics carry 20 OpenRX-Shared:
    lib_ids, so a fresh clone could not edit or place any symbol. Restored
    byte-exact from ec2c4f2^.
    - README board sizes now match Edge.Cuts: Lite and Lite-UFL 10.0 x 11.5 mm,
    Mono 10.0 x 17.3 mm. Gemini was already correct at 17.0 x 15.7 mm.
    - Remove the nine dead FLASHING.md links. The file is untracked and gitignored.
    Facts that only lived behind those links are inlined: the LR1121 DIO5-DIO8 to
    RFX2401C/SKY13373 mapping, the ExpressLRS 3.5.0 minimum, and the Mono/Gem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
2026-08-11 update all RXs rev2 with fab files
    [OpenRX-Lite-B_Cu.gbr, OpenRX-Lite-B_Mask.gbr, OpenRX-Lite-B_Paste.gbr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]
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2026-08-12 Rev 2 board work: routing optimisations, logo placement, 3D model fixes
    Routing reworked on Lite (segments 313 to 256, vias 60 to 89), Lite-UFL
    (317 to 269, 61 to 85) and Gemini (682 to 688, 196 to 243). ExpressLRS logo
    placed on Mono.
    3D model fixes on Gemini and Mono:
    - RFX2401C (U4, U7) pointed at QFN-16_L3.0-W3.0-H0.9-P0.50.wrl with an offset
    of (-951.61, 821.31, 0), so the body rendered about a metre off the board and
    the land looked bare in the viewer. Repointed at the RFX2401C model that
    OpenRX-Shared.pretty/QFN-16_L3.0-W3.0-P0.50-BL-EP1.7.kicad_mod specifies,
    offset zeroed, 270 degree rotation kept.
    - SKY13373 (U5, U8) carried no model reference at all. Added, matching the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
    [OpenRX-Lite.kicad_pcb]
2026-08-13 Standardise: six design docs into one AGENTS.md, trimmed README (#26)
    Adopts the org-wide shape for a multi-variant repo. The root DESIGN.md and the
    four per-variant DESIGN.md files become a single AGENTS.md: the family circuit,
    antennas, pad map, pin map and firmware targets once, then a section per
    variant. Cross-references between the old files become in-document anchors, all
    of which resolve.
    Every variant gains a .kicad_dru carrying the canonical block. Lite and
    Lite-UFL had none at all; Mono and Gemini had a single rule conditioned on a
    "50Ohm" netclass that no project in the org defines, so it could never fire.
    README drops the repository layout, build commands and per-variant detai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
2026-08-14 Normalise board setup to the line standard
    The canonical dru's copper-to-copper rule demanded 0.1 mm outer
    clearance against the 0.09 line standard stated in the same file,
    flooding DRC with false errors on standard-routed boards. Removed;
    the project-file floors gate this already. Rule floors set to the
    line standard where the routed board complies, verified by DRC:
    zero new violations.
2026-08-14 Drop the KiCad-Library submodule: nothing references it
    No symbol, footprint or 3D model in the design resolves through
    libs/KiCad-Library; every part is in the repo's local libraries. The
    submodule only cost --recursive clones and pin maintenance. Lib-table
    rows for the dead Incutec nickname removed so KiCad stops warning.
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2026-08-14 Rebuild E6 substitute STEP models from the trusted wrl geometry
    The .step files beside these .wrl models were different parts (USB-C
    3.5x oversized, etc), and the upstream LCSC .step is the same wrong
    file, so kicad-cli --subst-models shipped wrong geometry in every STEP
    export while the 3D viewer looked perfect. Rebuilt as tessellated STEP
    solids from the .wrl the viewer renders, via
    OpenDrone-Scripts/kicad/wrl_to_step.py: bbox and origin now match to
    0.000 mm. check_models reports zero E6, export unblocked.
    [OpenRX-Lite.kicad_pcb]
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2026-08-15 docs: standardise AGENTS.md, complete spec table, fix flash targets
    AGENTS.md rebuilt on the org template and fact-checked against the design files. README spec table completed (telemetry power, dimensions, 1.0 mm PCB for all variants) and maintainer added. FLASHING.md build targets corrected to opendrone.rx_2400.lite / .lite_ufl. DOC text variables cleaned of em dashes.
2026-08-22 3D models: retarget to KiCad stock, fix placement
    Replaces easyeda2kicad 3D models with KiCad's own where a dimension-matched
    equivalent exists. The easyeda models run 20-100x denser for the same package
    and most carry the LCEDA watermark modelled as raised geometry, which renders
    on every CAD picture of the board and is not on the real part.
    Only the (model ...) reference, offset and rotation are touched. No footprint,
    pad, land pattern, net, placement or value is modified. Applied to the footprint
    LIBRARY and the boards together: fixing only the .pretty is invisible because
    each board carries its own footprint copy, and fixing only the .kicad_pcb is
    surface level because the next placemen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
    [OpenRX-Lite.kicad_pcb]
2026-08-25 sch: standardise LCSC/Manufacturer/MPN fields across all variants
    Migrated LCSC part numbers out of variant-specific LCSC_Part fields into
    the standard LCSC field, and backfilled Manufacturer/MPN from the LCSC
    catalogue, on all four board variants (Gemini, Lite, Lite-UFL, Mono) and
    the shared ESP32-C3/SX1281 RX core sheet.
    kicad-skip reflowed each file on save, so the diffs are large but purely
    formatting; a structural S-expression diff and ERC re-run on all 12
    affected schematics (including the 4 unmodified top-level sheets) confirm
    only property values changed, no nets/placement/footprints touched.
    Known gap: L2/L3 in OpenRX-Gemini/esp32c3_lr1121_gemini.kicad_sch carry
    LCSC C1035, which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
    [esp32c3_sx1281_lite.kicad_sch]
2026-08-31 AGENTS.md: sync from the bench mirror rework (#45)
    Formatting repairs plus verified corrections from the 2026-08-31 bench
    session (fact-checked against datasheets, board READMEs and firmware
    sources). Details per file in OpenDrone-Testing commit 06034b3.
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2026-09-01 Split board into its own hardware repository
    [OpenRX-Lite-B_Cu.gbr, OpenRX-Lite-B_Mask.gbr, OpenRX-Lite-B_Paste.gbr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]
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2026-09-09 Give every placed part an LCSC field
    The BOM exporter reads a field named LCSC. Parts that carried only
    "LCSC Part" were dropped from the supplier BOM and the pick and place
    without a warning, and ESP32-C3, the 15uH DC-DC inductor and
    SKY13373-460LF carried no LCSC anywhere.
    Adds LCSC to the schematic symbols and mirrors it onto the board
    footprints, which is the only route for references created by a
    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
    [OpenRX-Lite.kicad_pcb, esp32c3_sx1281_lite.kicad_sch]
2026-09-09 Set the titleblock revision to rev2
    quote_pack.py syncs the titleblock from the release stem; recording it
    keeps the design source stable across exports.
    Claude-Session: https://claude.ai/code/session_01HXA6SP2VEuBZn7yMrez3es
    [OpenRX-Lite.kicad_pcb]
2026-09-09 Delete three orphan test pads off the board
    TP3, TP4 and TP5 each existed twice. The duplicates sat around 100 mm
    from the board, outside Edge.Cuts, and put copper on all six layers plus
    15 plated holes into the fabrication data: the shipped Gerbers spanned
    X 0.62 to 109.80 against an outline of X 100.00 to 110.00.
    The copies on the board keep the +5V, GND, TX, RX and BOOT nets, so the
    pads themselves are unchanged and the board now matches OpenRX-Lite-UFL,
    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
    [OpenRX-Lite.kicad_pcb]
2026-11-11 docs(rules): kicad-skip cannot round-trip KiCad 10 schematics (#12)
    Syncs the shared Rules section from OpenDrone-hw/hardware-template (PR 16).
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2026-11-12 Titleblock and Fabrication Toolkit archive name: rev2.3 (#14)
    rev2.3 is the batch 2 production revision (founder decision 12 Nov 2026:
    include the 1 Nov fix). The production adapter sets the titleblock to the
    release revision and stops when that changes the design source, so the
    board must say rev2.3 at the released commit; the archive name follows.
    Metadata only, written with the pcbnew API.
2026-11-14 README: describe OpenRX as a general-purpose radio control receiver module (#15)
    Requested by Stan, 14 Nov 2026: "fix the public readme's".
    - Opening lines: ExpressLRS radio control receiver module with telemetry, for cars, boats, robots and aircraft; technical facts unchanged.
    - Connection: serial (CRSF) on the RX/TX pads to a controller; a flight controller is named as one example.
    - PWM output is not claimed: the shipped ExpressLRS layout for this board defines no `pwm_outputs`, so the web UI offers no PWM channels.
    README text only; no KiCad files touched.
    Founder-session: 2026-11-14: Stan, 14 Nov 2026: "fix the public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
